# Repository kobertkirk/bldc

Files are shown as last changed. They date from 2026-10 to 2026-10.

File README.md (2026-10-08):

# 48 V / 35 A BLDC hub-motor controller

A KiCad hardware design plus STM32 firmware for a hall-sensored e-bike or scooter hub motor:

* **48 V nominal** (13S Li-ion, 54.6 V full). All power parts are rated 100 V and the TVS clamps at 60 V standoff.
* **35 A battery current limit** and 60 A phase current limit. Both are set in firmware and can be changed over UART.
* **Field-oriented control (FOC)** using the hall sensors, with angle interpolation, for quiet and smooth torque from standstill.
* **Throttle** input (standard 0.8–4.2 V hall throttle).
* **Momentary power button.** Press to switch on, hold for 2 s to switch off. Standby current is a few µA.
* **FWD/REV switch** input (switch to GND = reverse). There is also a **brake** input (switch to GND = cut power, optional regen).
* **UART telemetry and commands** (115200 8N1, 3.3 V). It streams every reading: voltage, currents, power, speed, temperatures, throttle, direction, faults, limits and energy used.
* **Auto-detect** measures motor R and L and learns the hall-sensor table, so any 120° hall hub motor works without setting angles by hand.

```
hardware/
  kicad/                 KiCad project (bldc48.kicad_pro): 4-sheet schematic + routed 4-layer PCB
  renders/               3D renders, routing/layer images, bldc48.glb 3D model
  bldc48-schematic.pdf   schematic as PDF
  bom.csv                bill of materials
  tools/                 circuit.py (the netlist source), generators, autorouting, connectivity checker,
                         render3d/ (VRML export + headless three.js renderer)
firmware/
  src/                   STM32G431 firmware (register-level, no HAL)
  sim/                   closed-loop PC simulation of the firmware against a hub-motor model
  cmsis/                 ST / ARM CMSIS headers (Apache-2.0)
```

> **Status — read this before building.** The schematic is complete and has been checked pin by pin (see
> [Verification](#verification)). The 90 × 95 mm (3.5 × 3.7 in) 4-layer, two-sided PCB (rev F) is **fully routed and passes KiCad
> DRC with 0 violations and 0 unconnected pads**. The power stage is placed by script around fixed columns; the signal
> routing was done by an autorouter (Freerouting), a small grid router for what it leaves open, and scripted copper
> pours, so have it reviewed before ordering. The firmware compiles and passes a detailed simulation, but it has
> **not been run on real hardware**. Bring the first board up with the current-limited procedure in
> [First power-up](#first-power-up).

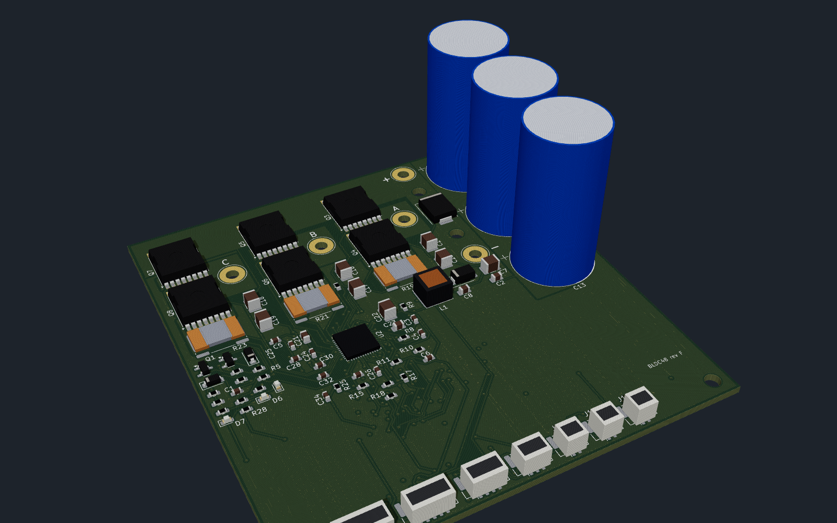
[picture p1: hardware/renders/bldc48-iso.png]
3D render of the routed board


---

## Block diagram

```
 BAT+ ──┬── TVS ── 3×1000µF + 6×2.2µF ──┬────────────────────────────────────┐
        │                                │  3 × half bridge (6 × IPT015N10N5) │
        │        ┌──────── DRV8353RS ────┴── GHx / GLx gate drive, SHx sense  ├── MOTOR A/B/C
        │        │  charge pump, 6-95 V buck → +5 V ── AP2112 → +3.3 V        │
        ├─Q1─────┤  3 × current-sense amp (G=20) ◄── 0.5 mΩ low-side Kelvin shunts
        │ latch  │  SPI config / fault readout, nFAULT
  PWR ──┘        └──► STM32G431CB ◄── ISENSE A/B/C, VBUS, throttle, NTCs
  button               │  ▲
              UART ◄───┘  └── halls, FWD/REV, brake, button
```

## Connectors

| Ref | Connector | Pin 1 | Pin 2 | Pin 3 | Pin 4 | Pin 5 | Pin 6 |
|---|---|---|---|---|---|---|---|
| J1 / J2 | 12 AWG solder pads (2.8 mm hole), right of the bridge | BAT+ / BAT− | | | | | |
| J3–J5 | 12 AWG solder pads, one per phase column | MOTOR A / B / C | | | | | |
| HALL | JST-GH 6 | +5 V | GND | Hall A | Hall B | Hall C | Motor NTC (optional) |
| THROTTLE | JST-GH 3 | +5 V | Signal | GND | | | |
| FWD/REV | JST-GH 2 | DIR (to GND = reverse) | GND | | | | |
| BRAKE | JST-GH 2 | BRAKE (to GND = braking) | GND | | | | |
| POWER_BTN | JST-GH 2 | PWR_SW (momentary to GND) | GND | | | | |
| UART | JST-GH 4 | +3.3 V out | TX (board → host) | RX (host → board) | GND | | |
| SWD | JST-GH 5 | +3.3 V | SWDIO | SWCLK | NRST | GND | |

All signal connectors are JST-GH (1.25 mm, latching) along the bottom edge. The power button and all signal wires
carry 3.3–5 V only, never battery voltage, so a cheap handlebar button is fine. Battery and phase wires are **12 AWG
silicone wire soldered straight into the plated pads** (strip 4 mm, push through, solder from the top; the pads are
via-stitched to the pours on all layers). Strain-relieve the wires to the case or heat plate with a cable tie so the
joints never carry the cable's weight. Put an **XT90-S anti-spark connector** and a **40 A fuse** in the battery
lead: the board has no reverse-polarity or inrush protection.

## First power-up

1. Flash the firmware over SWD (`cd firmware && make flash`).
2. Use a **bench supply at 48 V with a 2 A current limit**. Connect the UART (3.3 V USB-serial adapter at 115200 baud)
   and the halls, but leave the motor phases disconnected. Press the power button: the green LED blinks and telemetry
   lines (`$TLM,...`) appear. Type `status`. You should see vbus ≈ 48 V and `faults NOT_DETECTED`. Type `drv`:
   it should report `nFAULT=high` and zero status words (the DRV8353RS took its SPI settings).
3. Connect the motor phases (any order) and the hall connector. **Lift the wheel** so it spins freely.
4. Type `detect`. The wheel turns slowly forwards and then backwards (about 15 s total). Expected result:
   `detect OK: R = … mOhm, L = … uH, halls learned`. Type `save`.
   *(No UART cable? Hold the brake and full throttle for 3 s right after power-up, then release the throttle. Detect
   runs and saves automatically.)*
5. With the wheel still lifted, apply a little throttle. If the wheel turns the wrong way, `set dir_invert 1` then `save`.
6. Raise the supply limit (or switch to the battery) and set your limits, e.g. `set i_batt_max 35`, `set i_phase_max 60`,
   then `save`.

## UART interface

Lines end with CR or LF. Replies start with `>`. Telemetry lines start with `$TLM` (default every 100 ms;
change with `stream <ms>` or `stream off`).

```
$TLM,ms,state,faults,limits,vbus,ibus,power,ia,ib,ic,id,iq,iq_ref,erpm,rpm,mod,thr_v,thr_pct,dir,brake,hall,t_fet,t_mot,wh,ah,wh_regen
$TLM,105500,IDLE,0000,00,51.99,0.00,0.0,-0.01,0.01,-0.10,0.06,-0.00,0.00,2670,116.1,0.000,0.849,0.0,FWD,0,4,25.0,nan,10.912,0.2224,0.000
```
(Real line from the simulation: a coasting wheel at 116 rpm, 52 V, throttle at rest. `t_mot` is `nan` when no motor
NTC is enabled.)

| Command | What it does |
|---|---|
| `help` | List the commands |
| `status` | Human-readable state, faults, voltage, current, rpm, temperatures and control-loop CPU load |
| `tlm` / `hdr` | Print one telemetry line / print the column names |
| `stream <ms>` / `stream off` | Set the periodic telemetry rate, or turn it off |
| `get [name]` | Show one parameter, or all of them (including the learned hall angles) |
| `set <name> <value>` | Change a parameter in RAM |
| `save` / `defaults` | Write the config to flash / reload the defaults into RAM |
| `detect` / `detect r` / `detect l` / `detect hall` | Run auto-detect: everything, or only R, L or the hall table |
| `clear` | Clear latched faults |
| `drv` | DRV8353RS fault/status words, live and as captured at the last driver trip |
| `off` / `reboot` | Power the board off / restart the MCU |

Main parameters (`get` lists them all): `i_phase_max` 60 A, `i_batt_max` 35 A, `i_batt_regen` 5 A, `i_brake` 0 A (regen
on the brake input, off by default), `v_uv_start` 42 V / `v_uv_cut` 39 V (13S), `v_ov` 60 V, `t_fet_start` 80 °C /
`t_fet_max` 100 °C, `thr_min_v` 1.0 V / `thr_max_v` 4.0 V, `ramp_up` 100 A/s, `erpm_max` 0 (no speed limit),
`pole_pairs` 23 (only affects the rpm display), `mot_ntc_en` 0, `auto_off_min` 0.

| Fault bit (`faults` field, hex) | Meaning | Red LED blinks |
|---|---|---|
| 0x001 | overcurrent (80 A instantaneous phase-current trip) | 1 |
| 0x002 | overvoltage (> `v_ov`) | 2 |
| 0x004 | battery below `v_uv_cut` (no torque; information only) | short blink every 2 s |
| 0x008 | hall sensors invalid (000/111, e.g. unplugged) | 4 |
| 0x010 | throttle wire fault (< 0.4 V or > 4.7 V) | 5 |
| 0x020 | FET over-temperature or NTC broken | 6 |
| 0x040 | motor over-temperature (if `mot_ntc_en`) | 7 |
| 0x080 | halls not learned yet (run `detect`) | 8 |
| 0x100 | last detect failed | 9 |
| 0x200 | current-sensor offset out of range | 10 |
| 0x400 | throttle held at power-up | 11 |
| 0x800 | gate driver fault (DRV8353 nFAULT: VDS overcurrent, gate fault, UVLO, over-temperature); `drv` shows the fault words; the driver is re-initialised before it clears | 12 |

`limits` bits (why torque is reduced right now): 0x01 battery current, 0x02 phase current, 0x04 undervoltage
fold-back, 0x08 FET temperature, 0x10 motor temperature, 0x20 speed limit, 0x40 out of voltage (top speed),
0x80 stall protection.

Faults switch the gates off at once. They clear by themselves once the cause is gone and the throttle is back at
zero, so the motor can never restart while the throttle is held.

## How it works

**Power stage.** Six Infineon IPT015N10N5 (100 V, 1.5 mΩ, TOLL package) are driven directly by a TI DRV8353RS
smart gate driver (100 V, SPI). It sets the gate current itself (300 mA source / 600 mA sink, ≈100 ns edges on these
FETs), so there are no gate resistors; it adds 100 ns of its own dead time on top of the MCU's 400 ns and has a VDS
short-circuit trip (0.3 V, ≈110 A at 125 °C) behind the firmware's 80 A trip. Its SHx inputs sense each switch node
at the high-side source, right next to the gate pin. The MCU's TIM1 generates 20 kHz centre-aligned complementary
PWM (6-input mode). With the main output disabled, or with the driver asleep, all six gates are held low.

**Current sensing.** A 0.5 mΩ 4-terminal (Kelvin) shunt sits in each low-side source (Bourns CSS4J-4026R-L500F,
5 W). Its sense pads go to one of the DRV8353RS's three current-sense amplifiers (gain 20, biased to mid-rail), so full
scale is ±165 A per phase, comfortably above the 80 A hard trip (a compile-time check enforces this). The ADCs sample
while all three low-side FETs conduct, triggered by TIM1 channel 4 just before the counter peak. Above 90 % duty one
phase's low-side window is too short, so that phase's current is rebuilt from the other two (Ia + Ib + Ic = 0); the
duty is capped at 97 % so the bootstrap capacitors always recharge.

**Control.** The ADCs are triggered by the PWM timer once per period, and the injected-conversion interrupt runs the
FOC loop at 20 kHz:
- Clarke and Park transforms.
- PI current regulators on d and q, with BEMF/cross-coupling feed-forward and conditional-integration anti-windup.
- PWM delay compensation.
- Min/max SVPWM, capped at 97 % (low-side sensing needs a short low-side window; see above).

The rotor angle comes from the halls. Each hall edge gives the exact boundary angle, and between edges the angle is
extrapolated using a speed averaged over a full electrical revolution, which cancels sensor placement error. At
standstill the sector centre is used, which guarantees at least 86 % torque from the very first moment.

**Limits.**
- Throttle sets the torque (iq), with a ramp.
- Phase current limit.
- Battery current limit, from the power balance `I_bat = 1.5·vq·iq / Vbus`. In simulation it holds 34.8 A against a 35 A setting.
- Undervoltage, FET/motor temperature, speed and stall fold-backs.
- Instant 80 A hard trip and overvoltage trip.
- A direction change is only accepted once the wheel has stopped.

The motor flux linkage is learned while riding and used to re-engage smoothly at speed.

**Power latch.** When the button is pressed it pulls Q1's base (MMBTA92, 300 V PNP) low through 47 k and a diode.
Q1 enables the DRV8353RS's buck regulator. The MCU then sets PWR_HOLD, which turns on Q2 (MMBTA42) to keep Q1 on. A
BAT46W blocks the button-sense pull-up, so the latch cannot creep on through the unpowered 3.3 V rail. The buck's
enable divider also gives a ≈20 V UVLO. On shutdown the MCU first puts the gate driver to sleep, then releases the latch.

**Supplies.** The DRV8353RS's built-in 6–95 V buck (LM5008A core) makes +5 V for the halls, throttle and the
AP2112K-3.3 LDO; its 100 µH inductor is a 6 × 6 mm Bourns SRN6045TA. The gate drive comes from the DRV8353's own
charge pump (high side) and VGLS regulator (low side), so there is no 12 V rail and no separate gate-driver supply.
On power-up the firmware writes the driver's five configuration registers over SPI, reads them back and locks them;
a driver that does not answer stops the motor from starting (`drv` shows why).

## Verification

* `hardware/tools/check_netlist.py` exports KiCad's own netlist and checks that **every pin of all 133 parts** sits on
  the intended net, with no single-node nets. KiCad 7's CLI has no ERC, so this replaces it. A deliberately miswired
  pin is caught.
* KiCad DRC on the routed PCB: **0 violations, 0 unconnected pads, 0 footprint errors**, including the check that
  every footprint matches the stock KiCad library (report: `hardware/kicad/routing/drc.rpt`).
* `cd firmware && make sim` runs the **real** `motor.c`/`hall.c`/`cli.c` in closed loop against a model with:
  dead-time, PWM delay, ADC noise and offsets, 120° halls at an arbitrary offset, a 100 kg rider and a battery with
  internal resistance. It does this for two different motors. Results for motor 1:

  | Check | Result |
  |---|---|
  | Detect R / L / hall angles | 119.9 mΩ (120) / 259 µH (250) / 0.2° worst error |
  | Start from standstill, full throttle | torque ≥ 86 % of command from the first instant |
  | Peak phase current | 60.2 A (limit 60 A) |
  | Peak battery current (100 ms avg) | 34.3 A (limit 35 A) |
  | 120 A phase-short spike | hard trip, gates off within 200 µs |
  | Gate-driver fault (nFAULT) while riding | gates off within 2 PWM periods, driver re-initialised before restart |
  | High-duty current rebuild (low-side shunts) | exercised continuously at top speed, no faults |
  | Current-loop tracking | 0.47 A rms |
  | Top speed, 26″ wheel | ≈ 39 km/h (voltage limited) |
  | Coast, re-engage at speed, reverse, brake, throttle-wire break, hall unplug, low battery, overvoltage | all pass |

## Building the firmware

```
sudo apt install gcc-arm-none-eabi libnewlib-arm-none-eabi   # plus stlink-tools or openocd
cd firmware
make            # build/bldc48.elf/.bin/.hex  (~38 KB flash)
make flash      # st-flash, or: make flash-ocd
make sim        # closed-loop simulation on the PC
```

## Regenerating the hardware

The schematic, PCB and BOM are generated from `hardware/tools/circuit.py`, using symbols and footprints from the stock
KiCad libraries. After you edit the circuit, run `hardware/tools/regen.sh`. It needs KiCad ≥ 7; KiCad 8 and 9 open the
files directly.

`regen.sh` only places the parts. The board was then routed with
`hardware/tools/route_pcb.py --legacy --no-optimize --passes 30 --freerouting freerouting-1.9.0.jar`. This script:
- keeps tracks off the inner layers under the FETs, DC-link caps and shunts, and off the outer layers across the
  switch-node and low-side copper (rule areas)
- gives every GND pad outside the power stage its own via into the solid In1 plane, and puts a fixed "sense tap" via
  in each switch node next to the high-side gate pin for the DRV8353's SHx input
- routes the signals with Freerouting (headless, under `xvfb-run`)
- imports the result (KiCad 7 can only import a Specctra session from its GUI, so the script parses the file
  itself and restores any layer-change vias the router left out)
- `astar_route.py` is a small 4-layer grid router for connections Freerouting leaves open, keeping clear of the
  power copper
- adds the GND / +48V / +3V3 planes, the 35 A outer-layer pours and via arrays in the power pads, routes anything
  still cut off into its own pour, and stitches pour islands to the planes
- fills the zones and writes a DRC report

The routing session is saved in `hardware/kicad/routing/bldc48.ses` (with the DRC report next to it); `route_pcb.py
--ses ../kicad/routing/bldc48.ses` rebuilds a routed board from it, taking the part positions from the session. The
committed `bldc48.kicad_pcb` is the reference: a rebuild can differ in a few fan-out vias and then needs a DRC pass.

`hardware/tools/render3d/render.sh` exports the board to VRML with the KiCad 3D models (plus simple stand-ins for the
JST-GH connectors, the SRN6045 inductor and the DRV8353 QFN, whose models are not in the KiCad 7 library) and renders
the PNGs in `hardware/renders/` with three.js in headless Chromium; `layers.sh` makes the copper-layer images.

**Note:** regenerating overwrites placement and routing. For changes after this point, edit the board in KiCad and use
Tools → Update PCB from Schematic. The footprints are already linked to their schematic symbols for that.

### Board

| Overview | Power stage |
|---|---|
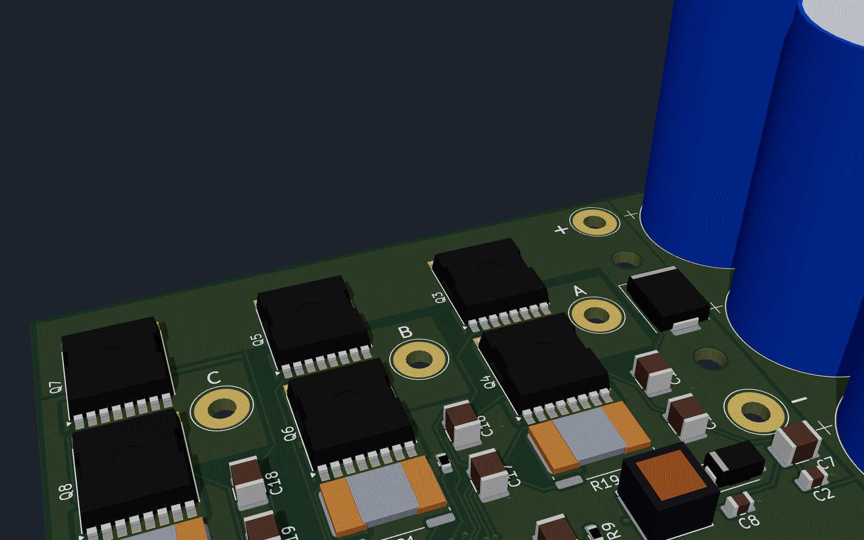
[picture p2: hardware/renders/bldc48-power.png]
power stage
| overview |  |
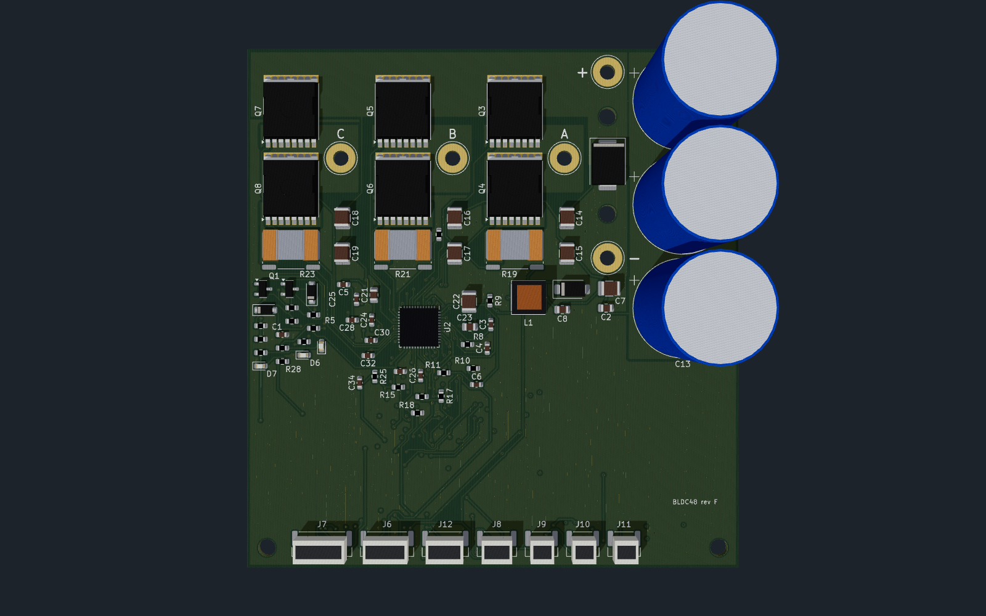
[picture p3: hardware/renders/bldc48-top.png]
top
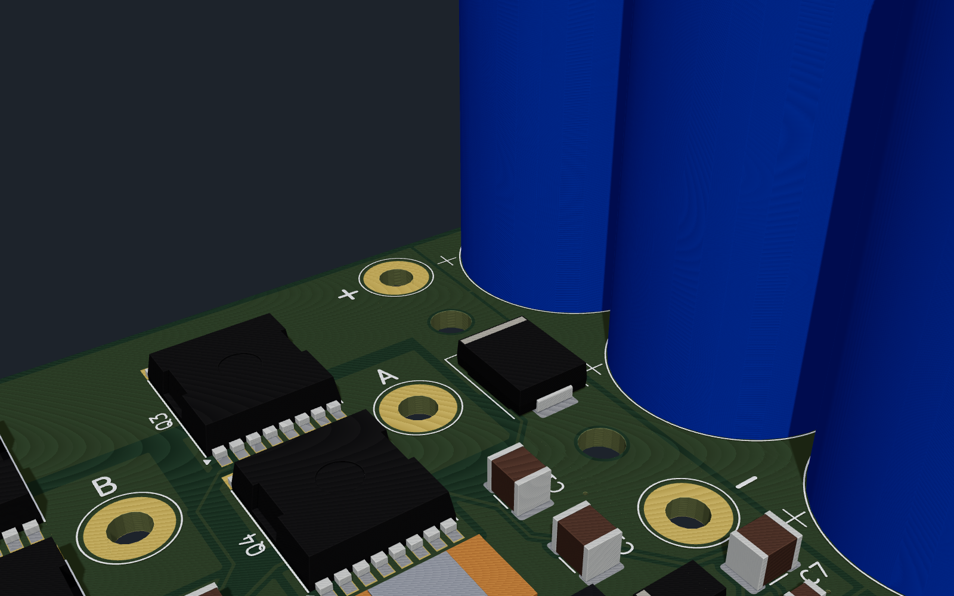
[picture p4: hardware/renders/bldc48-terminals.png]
wire pads
|  |  |

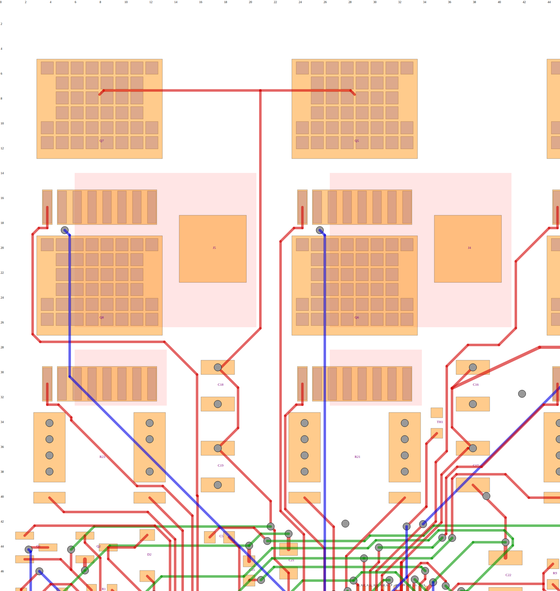
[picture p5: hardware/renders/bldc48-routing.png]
routing
Routing (tracks only, pours hidden): 

Copper layers: [top](hardware/renders/bldc48-layer-top.png) · [inner 1, GND](hardware/renders/bldc48-layer-in1.png) ·
[inner 2, +48V/+3V3](hardware/renders/bldc48-layer-in2.png) · [bottom](hardware/renders/bldc48-layer-bottom.png)

Stackup as built: F.Cu power stage, gate drive and signals, with pours (switch nodes, low-side sources, +48V bus,
GND fill) · In1.Cu solid GND plane · In2.Cu +48V under the power stage and +3V3 fill elsewhere, plus signals ·
B.Cu the same high-current pours under the bridge, the MCU and I/O parts, and signals. The inner planes are unbroken
under the FETs, DC-link caps and shunts. 1666 track segments and 269 vias; each switch-node and low-side pour is one
unbroken piece on both outer layers (checked by script).

## Rev F: DRV8353RS, 90 × 95 mm

Rev E (180 × 69.5 mm) was still too big. Rev F redesigns the circuit around one TI DRV8353RS smart gate driver and
puts the parts on both sides of a **90 × 95 mm** board, **68 % of rev E's area** (3.5 × 3.7 in instead of
7.1 × 2.7 in).
- **One chip instead of eight.** The DRV8353RS replaces the three LM5109B gate drivers, the three INA240A1 current
  amplifiers and both LM5164 bucks: it has the gate drive (charge pump + low-side regulator, no 12 V rail), three
  current-sense amplifiers and a 6–95 V buck that makes the +5 V rail.
- **Low-side shunts.** The three 0.5 mΩ Kelvin shunts now sit in the low-side sources (the DRV8353's amplifiers are
  low-side). The firmware samples while all low-side FETs conduct and rebuilds the third current above 90 % duty.
- **Three 1000 µF / 100 V** cans (Aishi ERS1KM102M35OT, 18 × 35 mm) in a column next to the bridge, plus two 2.2 µF
  ceramics straight across each half bridge. 3000 µF is still 1.7 × rev B's 1760 µF. Cans can be bent over before
  soldering if the case is low.
- **12 AWG wires soldered straight into the board** instead of M5 bolt terminals: battery pads at the right of the
  bridge, one motor pad per phase column. JST-GH (1.25 mm, latching) for all signal connectors.
- **Two-sided assembly.** Power stage, gate driver, supply and connectors on top; MCU, its filters and the I/O
  conditioning on the bottom, outside the heat-plate area under the FETs.
- The phase columns run C-B-A from left to right, following the DRV8353's pin order, so no phase's gate drive crosses
  another's. The labels are only names: auto-detect learns the hall/phase order.
- Signal tracks 0.2 mm with 0.15 mm clearance (JLCPCB's 4-layer minimum is 0.09 mm). The +48 V and switch-node pours
  keep 0.5 mm.

Each phase is a column: high-side FET, low-side FET, shunt, two 2.2 µF ceramics and the motor wire pad on the switch
node beside the FETs. The heat plate goes under the bridge (bottom side, no parts there).

## Ordering from JLCPCB (rough cost)

These are estimates from JLCPCB's published pricing and LCSC part prices in October 2026. Upload the files to get a
real quote, because their prices change often.

| Item (order of 5 assembled boards) | Approx. |
|---|---|
| 4-layer PCB 90 × 95 mm, 1.6 mm, 2 oz outer copper, 5 pcs | $30–50 |
| PCBA setup + stencils, **two-sided** (standard PCBA: both sides placed) | ≈ $50 |
| "Extended" LCSC part loading fee, ≈ $3 per unique part type (~22 types) | ≈ $65 |
| SMT + through-hole joints (≈ 530 SMT + 6 THT per board) | ≈ $10 |
| Parts (≈ $30/board, all from LCSC; the DRV8353RS is ≈ $6, the six FETs ≈ $15) | ≈ $150 |
| Shipping (DHL / FedEx) | $20–35 |
| **Total for 5** | **≈ $325–360, about $65–72 per board** |

The five 12 AWG wire pads are left for you to solder (wires are not assembled). Choosing JLCPCB's "economic" PCBA
is not possible for a board with parts on both sides; if cost matters more than size, rev E (one-sided, 180 ×
69.5 mm) is in the git history.

Every part in the BOM has an LCSC part number or is a generic resistor/capacitor/diode/connector that LCSC stocks in
quantity, so JLCPCB can build the whole board.
- The bulk capacitors are Aishi ERS1KM102M35OT (C724666): 1000 µF/100 V, 18 × 35 mm, 7.5 mm pitch, 10 000 h at
  105 °C. Aishi's "1K" voltage code is 100 V in its own scheme ("1B" is 80 V), and LCSC lists the part as 100 V.
- Ripple: at 35 A battery current the DC link carries roughly 17 A rms, ≈ 5.7 A per can with three cans; the ceramics
  take the high-frequency part. Expect the cans to run warm in sustained hard use: watch their temperature, or lower
  `i_batt_max` / `i_phase_max`, or fit higher-ripple parts (Panasonic EEU-FC2A102, Nichicon UHE2A102).
- The shunts are Bourns CSS4J-4026R-L500F (LCSC/JLCPCB C2076423, 0.5 mΩ ±1 %, 5 W, 4-terminal). The footprint is
  KiCad's `R_Shunt_Isabellenhuette_BVR4026` (same 10.6 mm span and pad layout).
- The DRV8353RS is TI DRV8353RSRGZR (LCSC C506246), VQFN-48 7 × 7 mm with an exposed pad. Its exposed pad has a
  thermal-via array into the GND plane; ask for the vias to be tented or plugged.
- Check that every part you order has a 100 V rating where the BOM needs one: the TOLL FETs, DRV8353RS, the
  1000 µF/100 V caps, the 100 V ceramics and the SS110 diode. Do not let the assembly service substitute
  lower-voltage parts.
- Set the stackup to 2 oz outer copper. JLCPCB's cheap 4-layer offer is 1 oz.
- JLCPCB only assembles from 2 boards upward, and the setup and part-loading fees are charged once per order, so
  most of the cost of a small order is fees.
- Board size: 90 × 95 mm (3.5 × 3.7 in), 1.6 mm thick. The 1000 µF caps are the tallest parts, so the assembled
  board is about 37 mm tall (less if the caps are bent over). Four M3 holes: two in the battery strip, two in the
  bottom corners.

## Design review (rev B, kept for reference)

A full review of rev A found and fixed these problems:

| Problem in rev A | Fix in rev B |
|---|---|
| BAT+ / BAT− were 5×10 mm SMD solder pads 7.5 mm apart (≈2.5 mm copper gap), 6 mm in from the edge; SMD pads tear off under 12 AWG wire strain | M5 plated bolt terminals for ring lugs, via-stitched to the planes, on the left edge 36 mm apart, TVS between them, large BAT+/BAT− silkscreen |
| Motor pads sat 38 mm below their shunts | M5 bolt terminals on the bottom edge straight below each shunt, labelled MOTOR A/B/C |
| **Overcurrent trip could never fire**: INA240A2 (gain 50) saturated the ADC at ±66 A, below the 80 A trip | INA240A1 (gain 20, ±165 A full scale); a compile-time assert keeps the trip inside the measurable range; new simulation test trips on a 120 A spike within 200 µs |
| INA240 inputs tapped the switch-node/phase copper anywhere, so pour resistance corrupted the current reading | 4-terminal Kelvin shunt (Bourns CSS4J-4026R-L500F, 5 W) with dedicated sense pads to the amplifier |
| FET temperature sensor TH1 was in the board corner, far from the FETs | TH1 next to the middle low-side FET |
| DC-link ceramics ~32 mm from the low-side sources (large switching loop) | Ceramics directly under each low-side FET's source leads; both FETs drain-tab up so the switch node is a short gap between them |
| Low-side gate on the far side of the FET from its driver | Driver beside the FET pair, both gate pins facing it |
| Router ran signals on In2 straight under the FETs, slotting the +48V plane between the drains and the ceramics | Rule area keeps tracks off both inner layers under the FETs, ceramics and shunts |
| 10 Ω gate resistors: ≈170 ns edges, ≈2.9 W switching loss per high-side FET at 35 A | 4.7 Ω: ≈100 ns edges, ≈1.7 W |
| 6 × 220 µF carried ≈2.8 A rms ripple each | 8 × 220 µF, ≈2.1 A each |
| Pours sized from pad centres missed the TOLL drain tabs' real outline (vias in the tabs connected on one layer only) | Pours drawn from the measured pad outlines; inner planes solid-connected to the power terminals |

Checks run on rev B: every symbol pin matches its footprint pad (29 symbol/footprint pairs), every pin of all 174
parts is on its intended net, every footprint matches the stock KiCad library, KiCad DRC 0 violations, firmware
simulation passes on two motors including the new overcurrent test.

## PCB layout rules

* Use 4 layers with 2 oz outer copper. Run 35 A battery and phase paths as wide pours on two or more layers,
  stitched with many vias. Rule areas keep signal tracks off the switch-node and low-side copper on the top layer;
  do not route across them.
* Keep each half-bridge loop (high FET → low FET → 2.2 µF ceramics) as small as possible. The bulk caps sit right
  next to the bridge.
* Give the FET drain/source pads thermal-via arrays down to the bottom pours. Bolt the board to an aluminium plate or
  the case through a thermal pad under the bridge (no parts on the bottom there). At 35 A, expect roughly 6–10 W of
  losses at full load.
* Route each shunt's sense pads (pins 2/3 of the 4-terminal shunt) to the DRV8353's SPx/SNx as a pair, with the
  1 nF filter caps at the driver.
* Keep the gate-drive traces short and away from the switch nodes; the DRV8353's SHx pin senses each switch node at
  the high-side source, next to the gate pin. Use one solid ground plane, and keep the MCU and analog parts away from
  the switching nodes.
* Keep TH1 (the NTC) next to the low-side FETs, which run hottest.

## Things to double-check against datasheets before ordering

* The DRV8353RS buck (LM5008A core) component values (RT / shutdown divider, 100 µH inductor, 4.02 k / 4.02 k
  feedback divider, 8.2 k / 47 nF / 330 pF ripple injection) were chosen with the datasheet formulas but not run
  through TI WEBENCH.
* The DRV8353's gate-current setting (300 mA / 600 mA) and the gate-drive trace lengths: the longest gate trace is
  ≈ 60 mm (phase C high side). The driver's current-mode drive tolerates this, but look at the gate waveform on the
  first board and lower IDRIVE if it rings.
* The bulk capacitor ripple rating (≈ 5.7 A rms per can at 35 A battery current; see above).
* Choose `v_uv_*` for your pack. The defaults are for 13S.

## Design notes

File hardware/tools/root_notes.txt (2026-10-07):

DESIGN SUMMARY
- Battery: 48 V nominal (13S Li-ion, 54.6 V full). Abs. max 60 V (TVS SMCJ60CA, 100 V FETs/drivers/bucks).
- Battery current limit 35 A (firmware, from FOC power estimate). Phase current limit 60 A (firmware), hard trip 80 A.
- Power stage: 6 x IPT015N10N5 (100 V, 1.5 mOhm, TOLL) driven by 3 x LM5109B half-bridge drivers @ 20 kHz, 4.7 Ohm gate resistors.
- Current sensing: in-line 0.5 mOhm 4-terminal (Kelvin) phase shunts + INA240A1 (G=20, mid-rail ref) -> +/-165 A full scale.
- Control: STM32G431CB @170 MHz, hall-sensor FOC with angle interpolation; hall/R/L auto-detect over UART.
- Supplies: LM5164 48->12 V (gate drive), LM5164 48->5 V (halls/throttle), AP2112 5->3.3 V (logic).
- Soft power: momentary button to GND wakes the bucks via Q1, MCU latches with PWR_HOLD; long press = off.
- I/O: hall + motor NTC (JST-PH6), throttle (PH3), FWD/REV switch (PH2), brake (PH2), power button (PH2),
  UART 115200 8N1 3.3 V (PH4: 3V3, TX, RX, GND), SWD (1x5 header).
LAYOUT RULES: 2 oz copper min (4 layer preferred), bus/phase pours >= 10 mm wide, FET tabs on thermal-via arrays
to an aluminium heat spreader, Kelvin-route INA240 inputs from the shunt pads, DC-link ceramics at each half bridge.

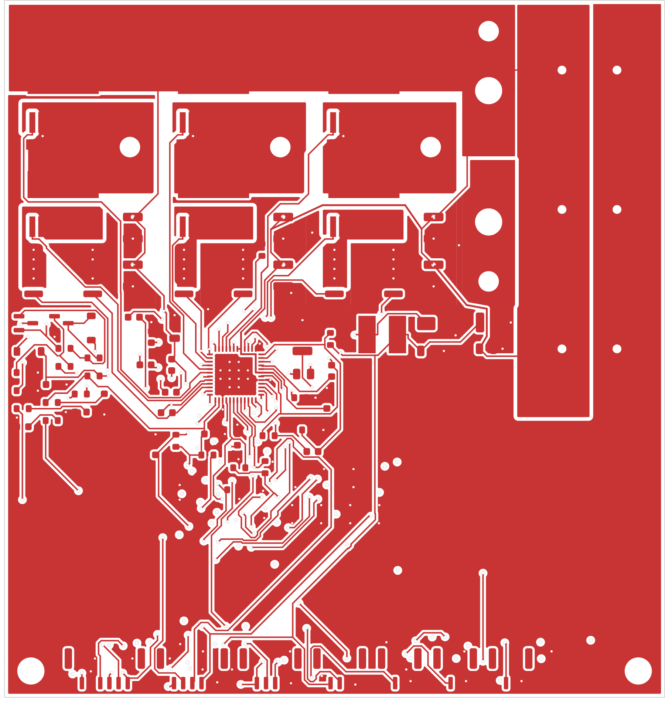
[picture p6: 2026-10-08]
hardware/renders/bldc48-layer-top.png

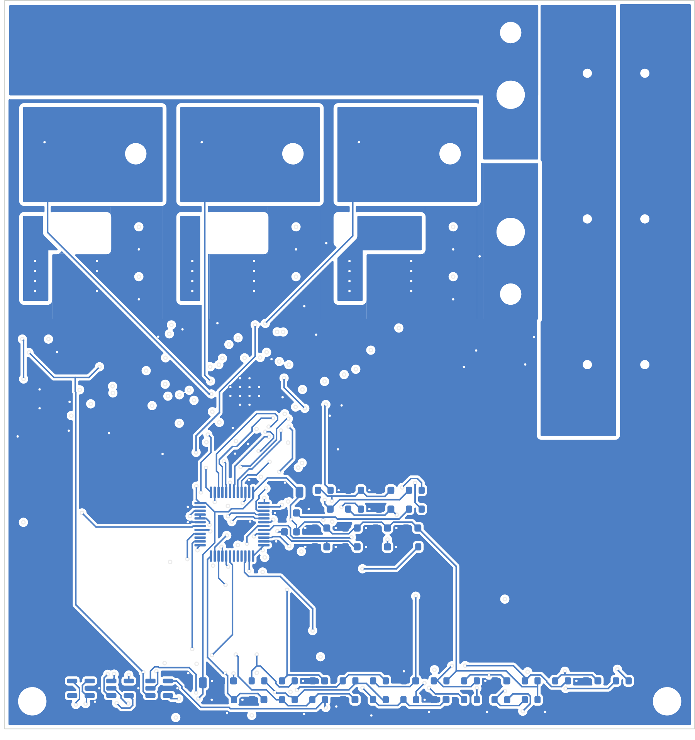
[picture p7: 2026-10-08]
hardware/renders/bldc48-layer-bottom.png

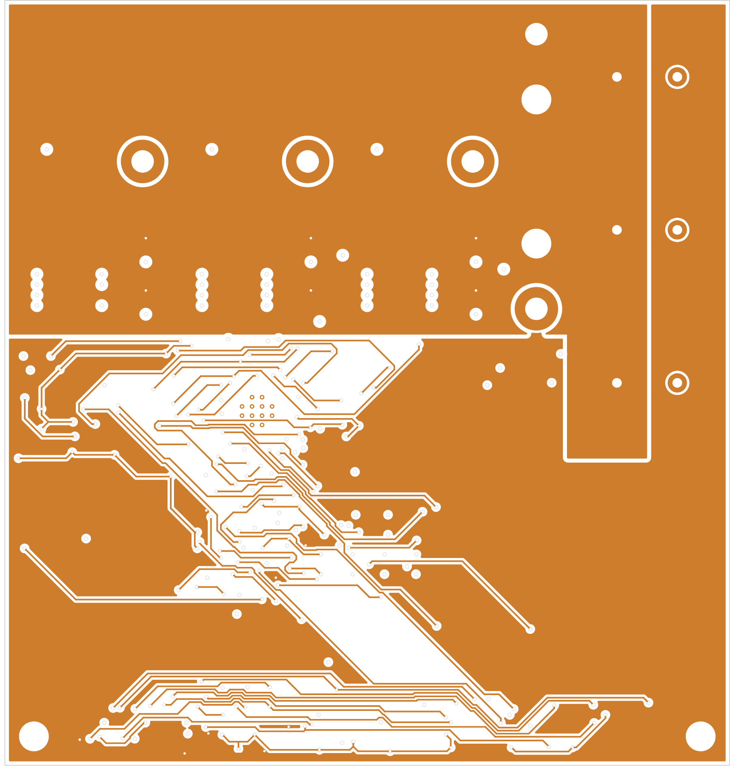
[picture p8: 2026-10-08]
hardware/renders/bldc48-layer-in2.png

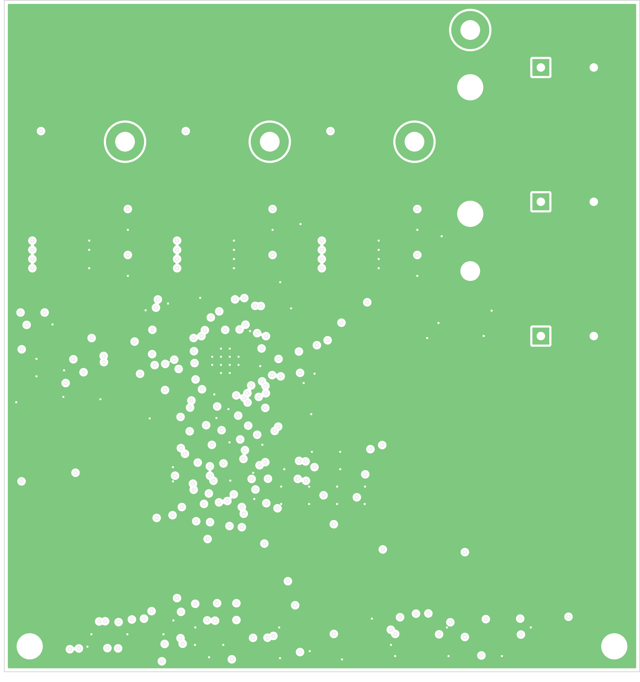
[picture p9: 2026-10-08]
hardware/renders/bldc48-layer-in1.png

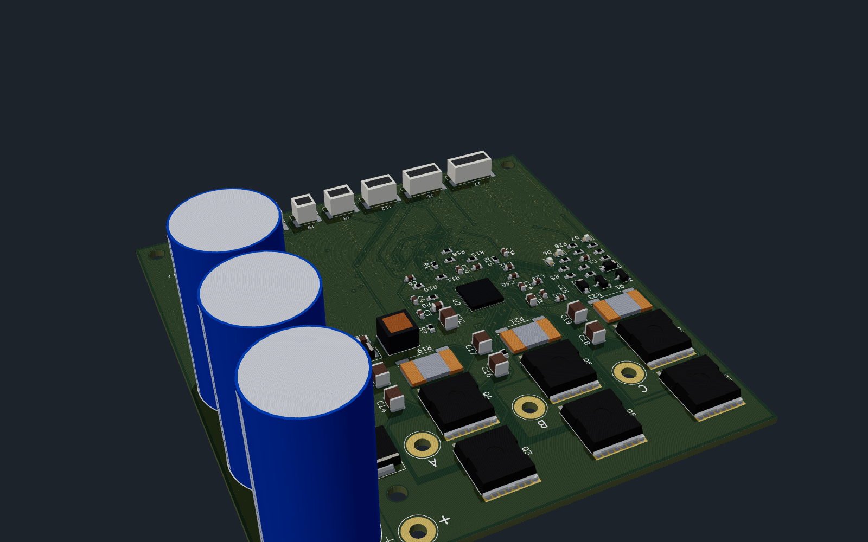
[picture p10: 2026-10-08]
hardware/renders/bldc48-rear.png

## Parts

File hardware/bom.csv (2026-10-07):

Qty | Value | Footprint | Part / notes | References
3 | 1000u/100V | CP_Radial_D18.0mm_P7.50mm | Aishi ERS1KM102M35OT (LCSC C724666), 18x35 mm, 7.5 mm pitch, 105 C 10000 h | C11 C12 C13
12 | 100n | C_0603_1608Metric |  | C27 C34 C35 C36 C37 C38 C41 C42 C46 C47 C48 C49
1 | 100n/100V | C_0805_2012Metric | X7R 0805 100V | C21
3 | 10n | C_0603_1608Metric |  | C1 C3 C20
9 | 1n | C_0603_1608Metric |  | C28 C29 C30 C31 C32 C33 C43 C44 C45
4 | 1u | C_0603_1608Metric |  | C4 C9 C26 C40
1 | 1u/100V | C_0805_2012Metric |  | C2
2 | 1u/16V | C_0603_1608Metric |  | C24 C25
7 | 2.2u/100V | C_1210_3225Metric | X7R 1210 100V (e.g. GRM32ER72A225KA35) | C14 C15 C16 C17 C18 C19 C22
1 | 22u/10V | C_1210_3225Metric | X5R/X7R 1210 10V | C7
1 | 330p | C_0603_1608Metric |  | C6
3 | 4.7u | C_0805_2012Metric |  | C8 C10 C39
1 | 47n | C_0603_1608Metric |  | C5
1 | 47n/100V | C_0805_2012Metric |  | C23
1 | 1N4148W | D_SOD-123 | 100V signal diode SOD-123 | D2
1 | BAT46W | D_SOD-123 | 100V Schottky SOD-123 | D3
2 | ESDA6V1-5SC6 | SOT-23-6 | ST ESDA6V1-5SC6 (LCSC C6650) | D8 D9
2 | GREEN | LED_0603_1608Metric |  | D5 D6
1 | RED | LED_0603_1608Metric |  | D7
1 | SMCJ60CA | D_SMC | TVS 60V standoff, 1500W, SMC (Littelfuse, LCSC C151290) | D1
1 | SS110 | D_SMA | 100 V 1 A Schottky, SMA (e.g. MDD SS110) | D4
1 | 600R@100MHz | L_0603_1608Metric |  | FB1
4 | M3 | MountingHole_3.2mm_M3 |  | H1 H2 H3 H4
1 | BAT+ | SolderWire_12AWG_D2.8mm_OD5.4mm | 12 AWG wire, soldered | J1
1 | BAT- | SolderWire_12AWG_D2.8mm_OD5.4mm | 12 AWG wire, soldered | J2
1 | BRAKE | JST_GH_BM02B-GHS-TBT_1x02-1MP_P1.25mm_Vertical | JST BM02B-GHS-TBT (1.25 mm, latching) | J10
1 | FWD/REV | JST_GH_BM02B-GHS-TBT_1x02-1MP_P1.25mm_Vertical | JST BM02B-GHS-TBT (1.25 mm, latching) | J9
1 | HALL | JST_GH_BM06B-GHS-TBT_1x06-1MP_P1.25mm_Vertical | JST BM06B-GHS-TBT (1.25 mm, latching) | J7
1 | MOTOR_A | SolderWire_12AWG_D2.8mm_OD5.4mm | 12 AWG wire, soldered | J3
1 | MOTOR_B | SolderWire_12AWG_D2.8mm_OD5.4mm | 12 AWG wire, soldered | J4
1 | MOTOR_C | SolderWire_12AWG_D2.8mm_OD5.4mm | 12 AWG wire, soldered | J5
1 | POWER_BTN | JST_GH_BM02B-GHS-TBT_1x02-1MP_P1.25mm_Vertical | JST BM02B-GHS-TBT (1.25 mm, latching) | J11
1 | SWD | JST_GH_BM05B-GHS-TBT_1x05-1MP_P1.25mm_Vertical | JST BM05B-GHS-TBT (1.25 mm, latching) | J6
1 | THROTTLE | JST_GH_BM03B-GHS-TBT_1x03-1MP_P1.25mm_Vertical | JST BM03B-GHS-TBT (1.25 mm, latching) | J8
1 | UART | JST_GH_BM04B-GHS-TBT_1x04-1MP_P1.25mm_Vertical | JST BM04B-GHS-TBT (1.25 mm, latching) | J12
1 | 100u | L_Bourns_SRN6045TA | Bourns SRN6045TA-101M or eq. (100 uH, Isat >= 0.5 A, 6x6 mm) | L1
6 | IPT015N10N5 | Infineon_PG-HSOF-8-1 | Infineon IPT015N10N5ATMA1 (LCSC C108964) | Q3 Q4 Q5 Q6 Q7 Q8
1 | MMBTA42 | SOT-23 |  | Q2
1 | MMBTA92 | SOT-23 |  | Q1
3 | 0.5m | R_Shunt_Isabellenhuette_BVR4026 | Bourns CSS4J-4026R-L500F (LCSC C2076423), 0.5 mOhm 1% 5 W | R19 R21 R23
5 | 100R | R_0603_1608Metric |  | R20 R22 R24 R43 R44
6 | 100k | R_0603_1608Metric |  | R1 R4 R6 R8 R13 R18
10 | 10k | R_0603_1608Metric |  | R3 R5 R15 R17 R25 R26 R35 R39 R41 R45
1 | 12k | R_0603_1608Metric |  | R37
1 | 150k | R_0603_1608Metric |  | R7
8 | 1k | R_0603_1608Metric |  | R27 R28 R30 R32 R34 R36 R40 R42
4 | 2.2k | R_0603_1608Metric |  | R12 R29 R31 R33
1 | 22k | R_0603_1608Metric |  | R38
2 | 4.02k | R_0603_1608Metric |  | R9 R10
1 | 4.7k | R_0603_1608Metric |  | R16
1 | 47k | R_0603_1608Metric |  | R2
1 | 5.6k | R_0603_1608Metric |  | R14
1 | 8.2k | R_0603_1608Metric |  | R11
1 | 10k B3435 | R_0603_1608Metric | Murata NCP18XH103F03RB (LCSC C13564) | TH1
1 | AP2112K-3.3 | SOT-23-5 | Diodes AP2112K-3.3TRG1 (LCSC C51118) | U1
1 | DRV8353RS | TI-RGZ-48-QFN | TI DRV8353RSRGZR (LCSC C506246) | U2
1 | STM32G431CBT6 | LQFP-48_7x7mm_P0.5mm | ST STM32G431CBT6 (LCSC C529355) | U3

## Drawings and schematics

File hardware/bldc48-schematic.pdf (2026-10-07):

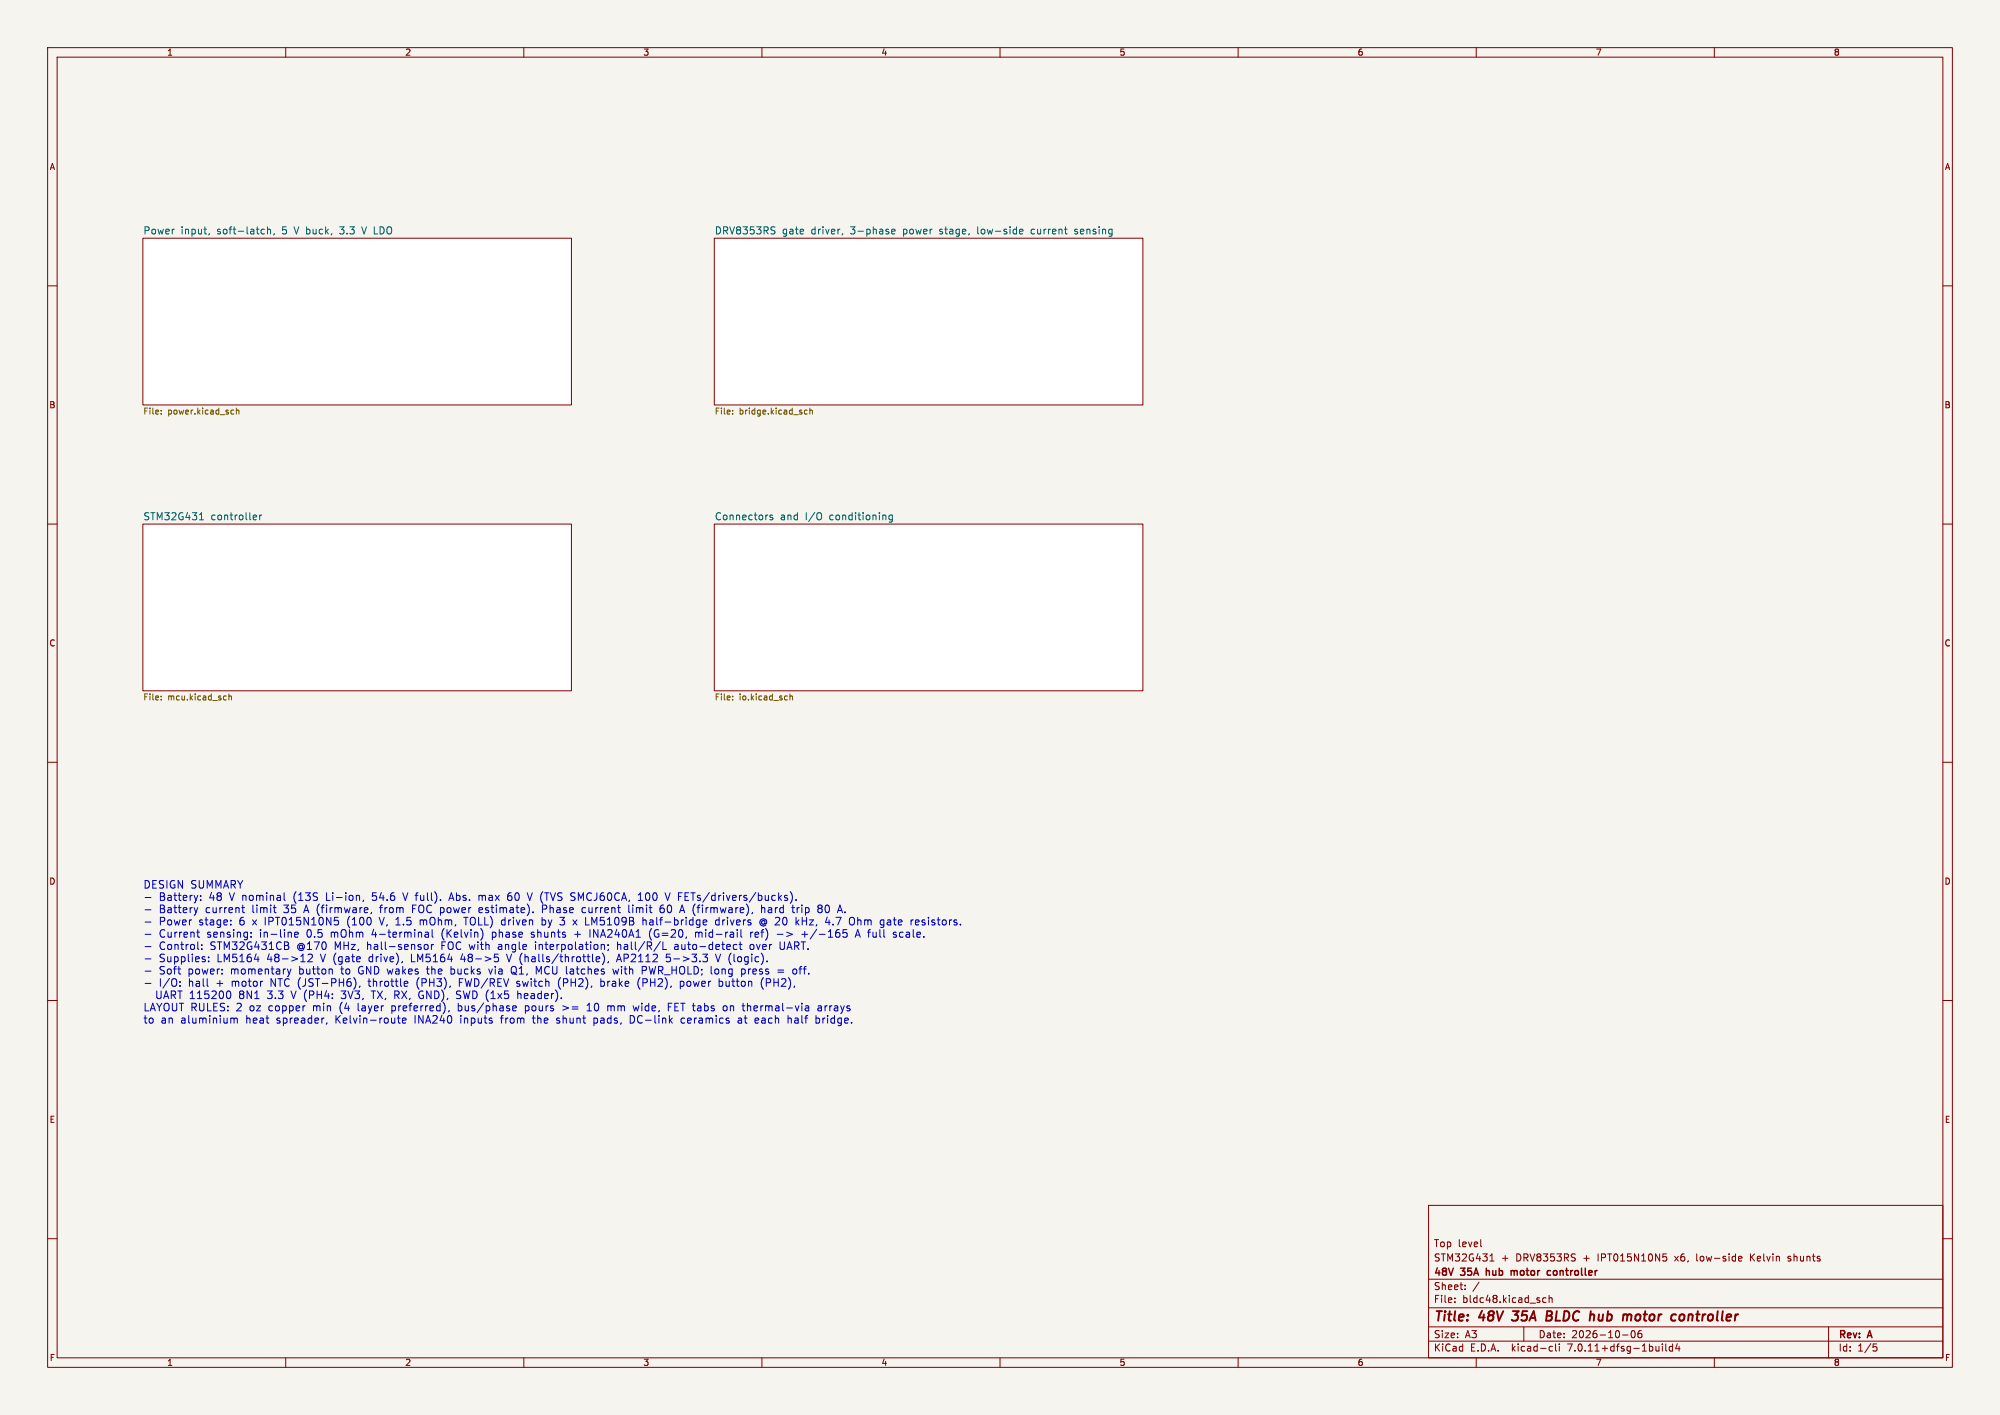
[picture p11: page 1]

UART 115200 8N1 3.3 V (PH4: 3V3, TX, RX, GND), SWD (1x5 header).

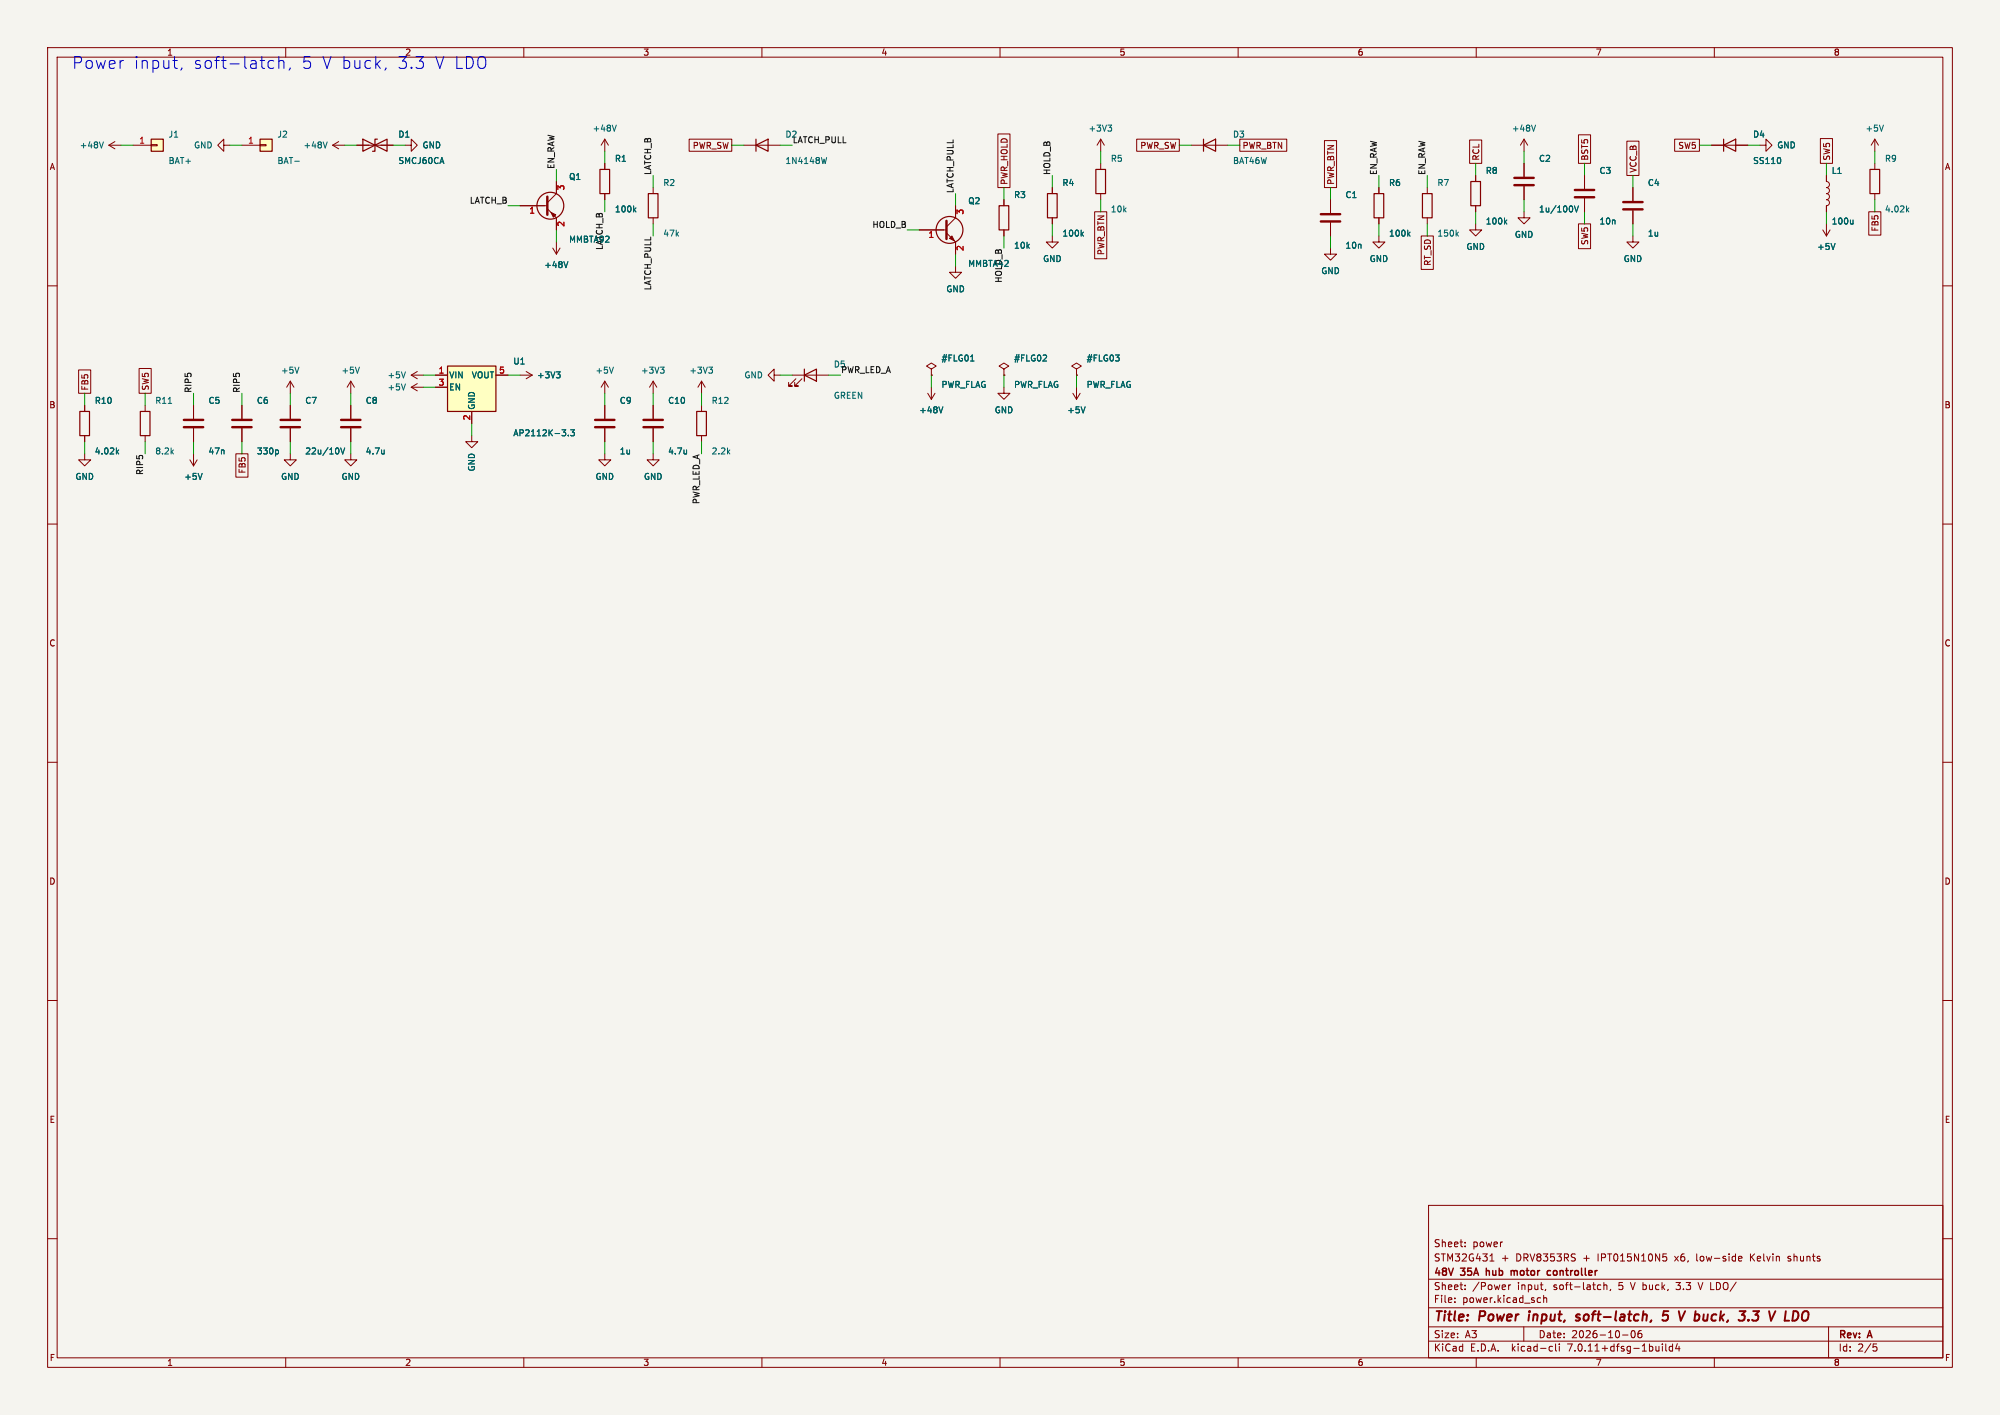
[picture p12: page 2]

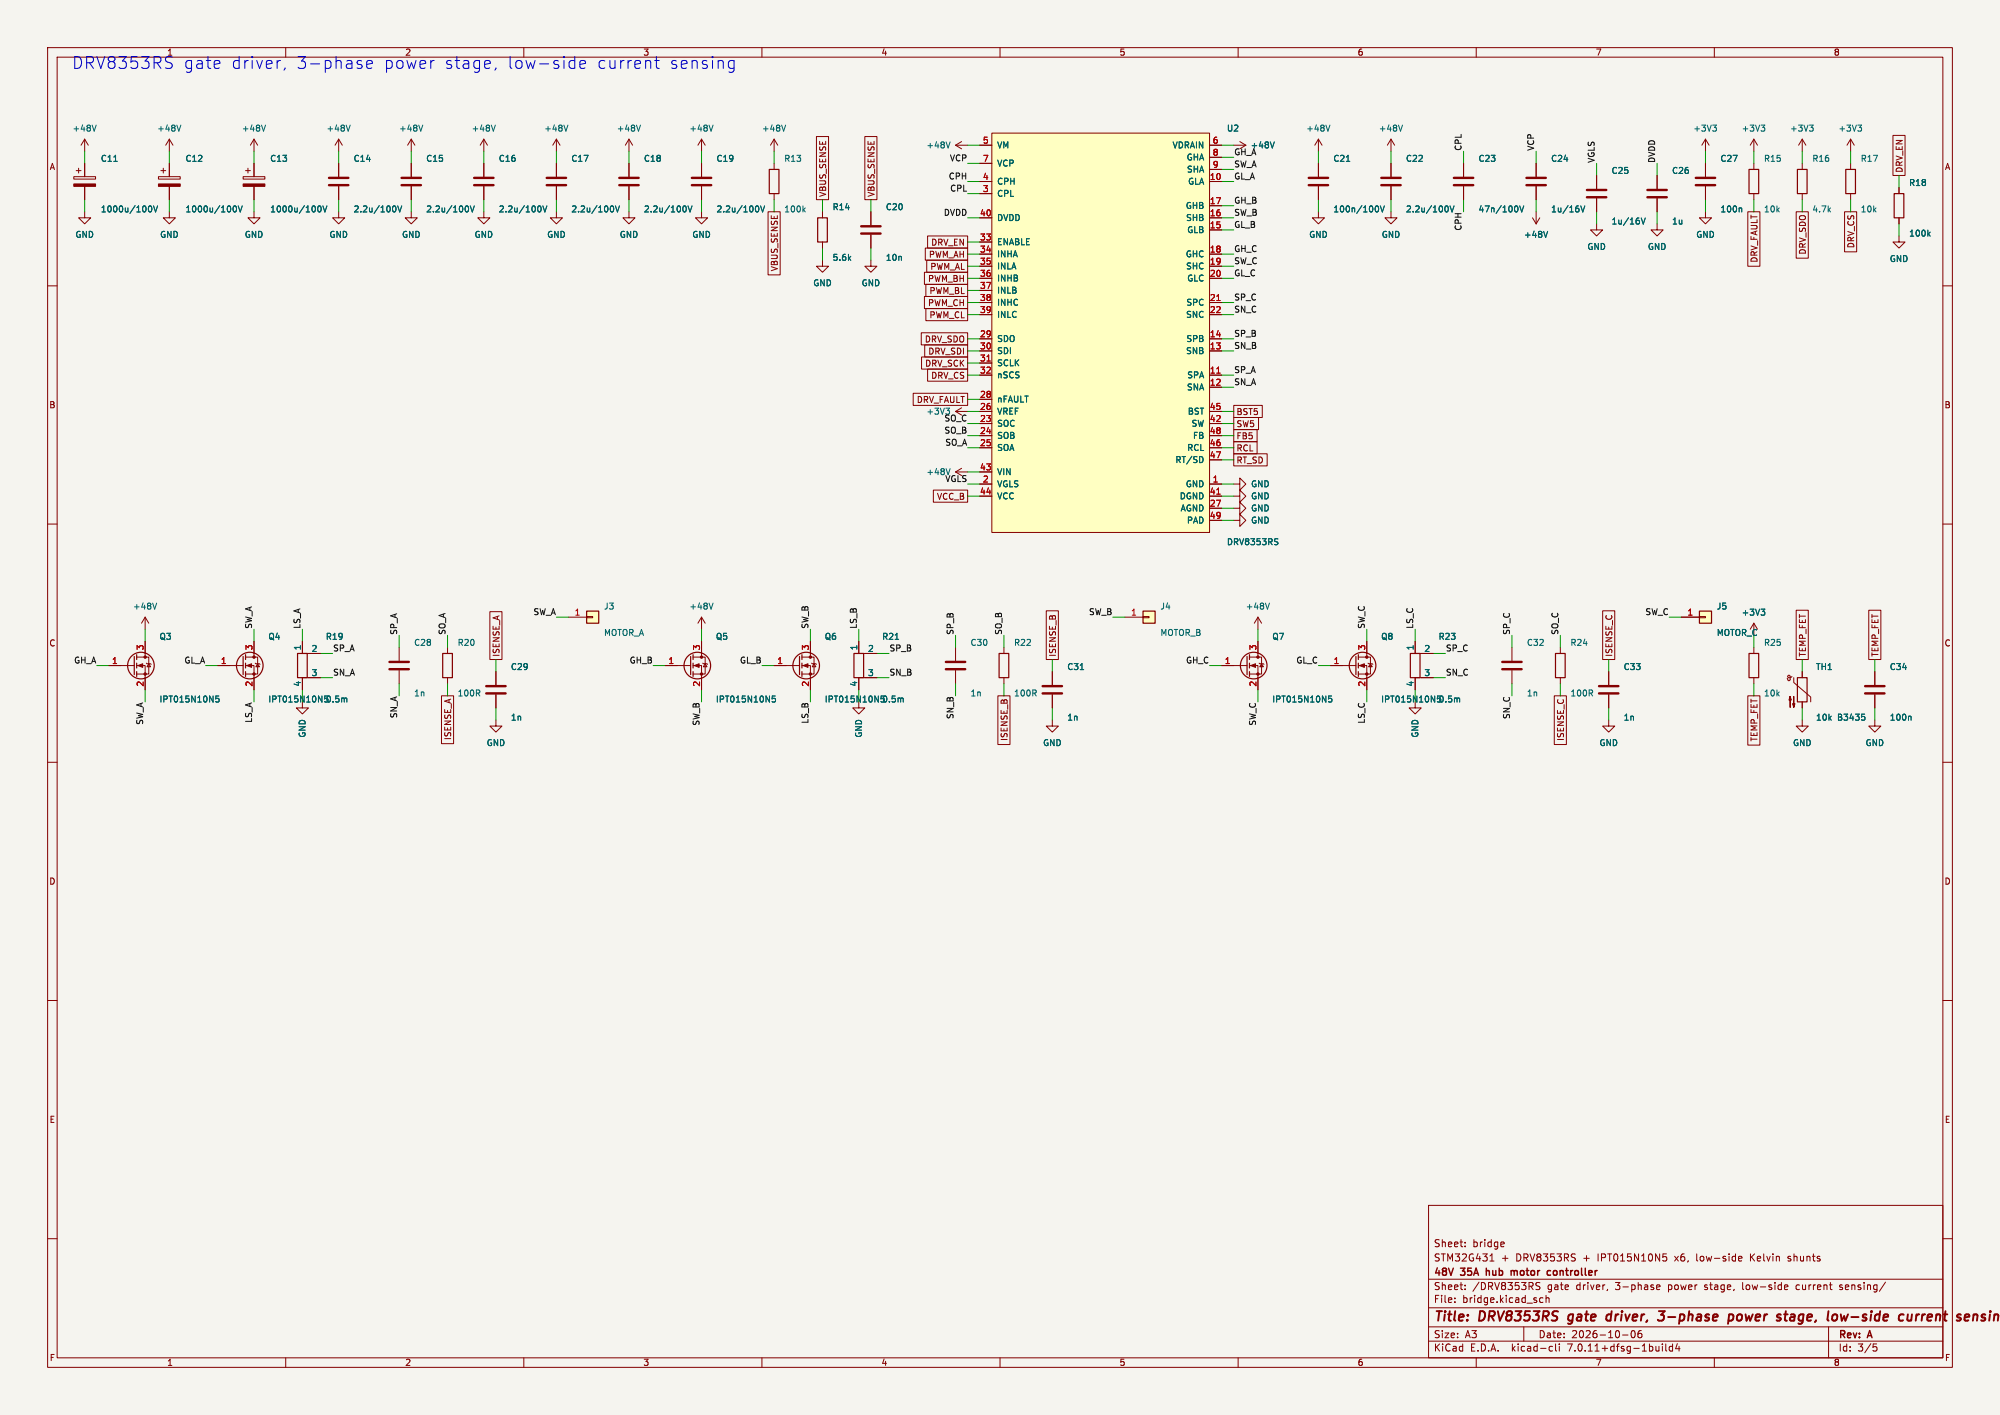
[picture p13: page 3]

CPH
nFAULT 28 SDO 29 CPL 3 SDI 30 SCLK 31

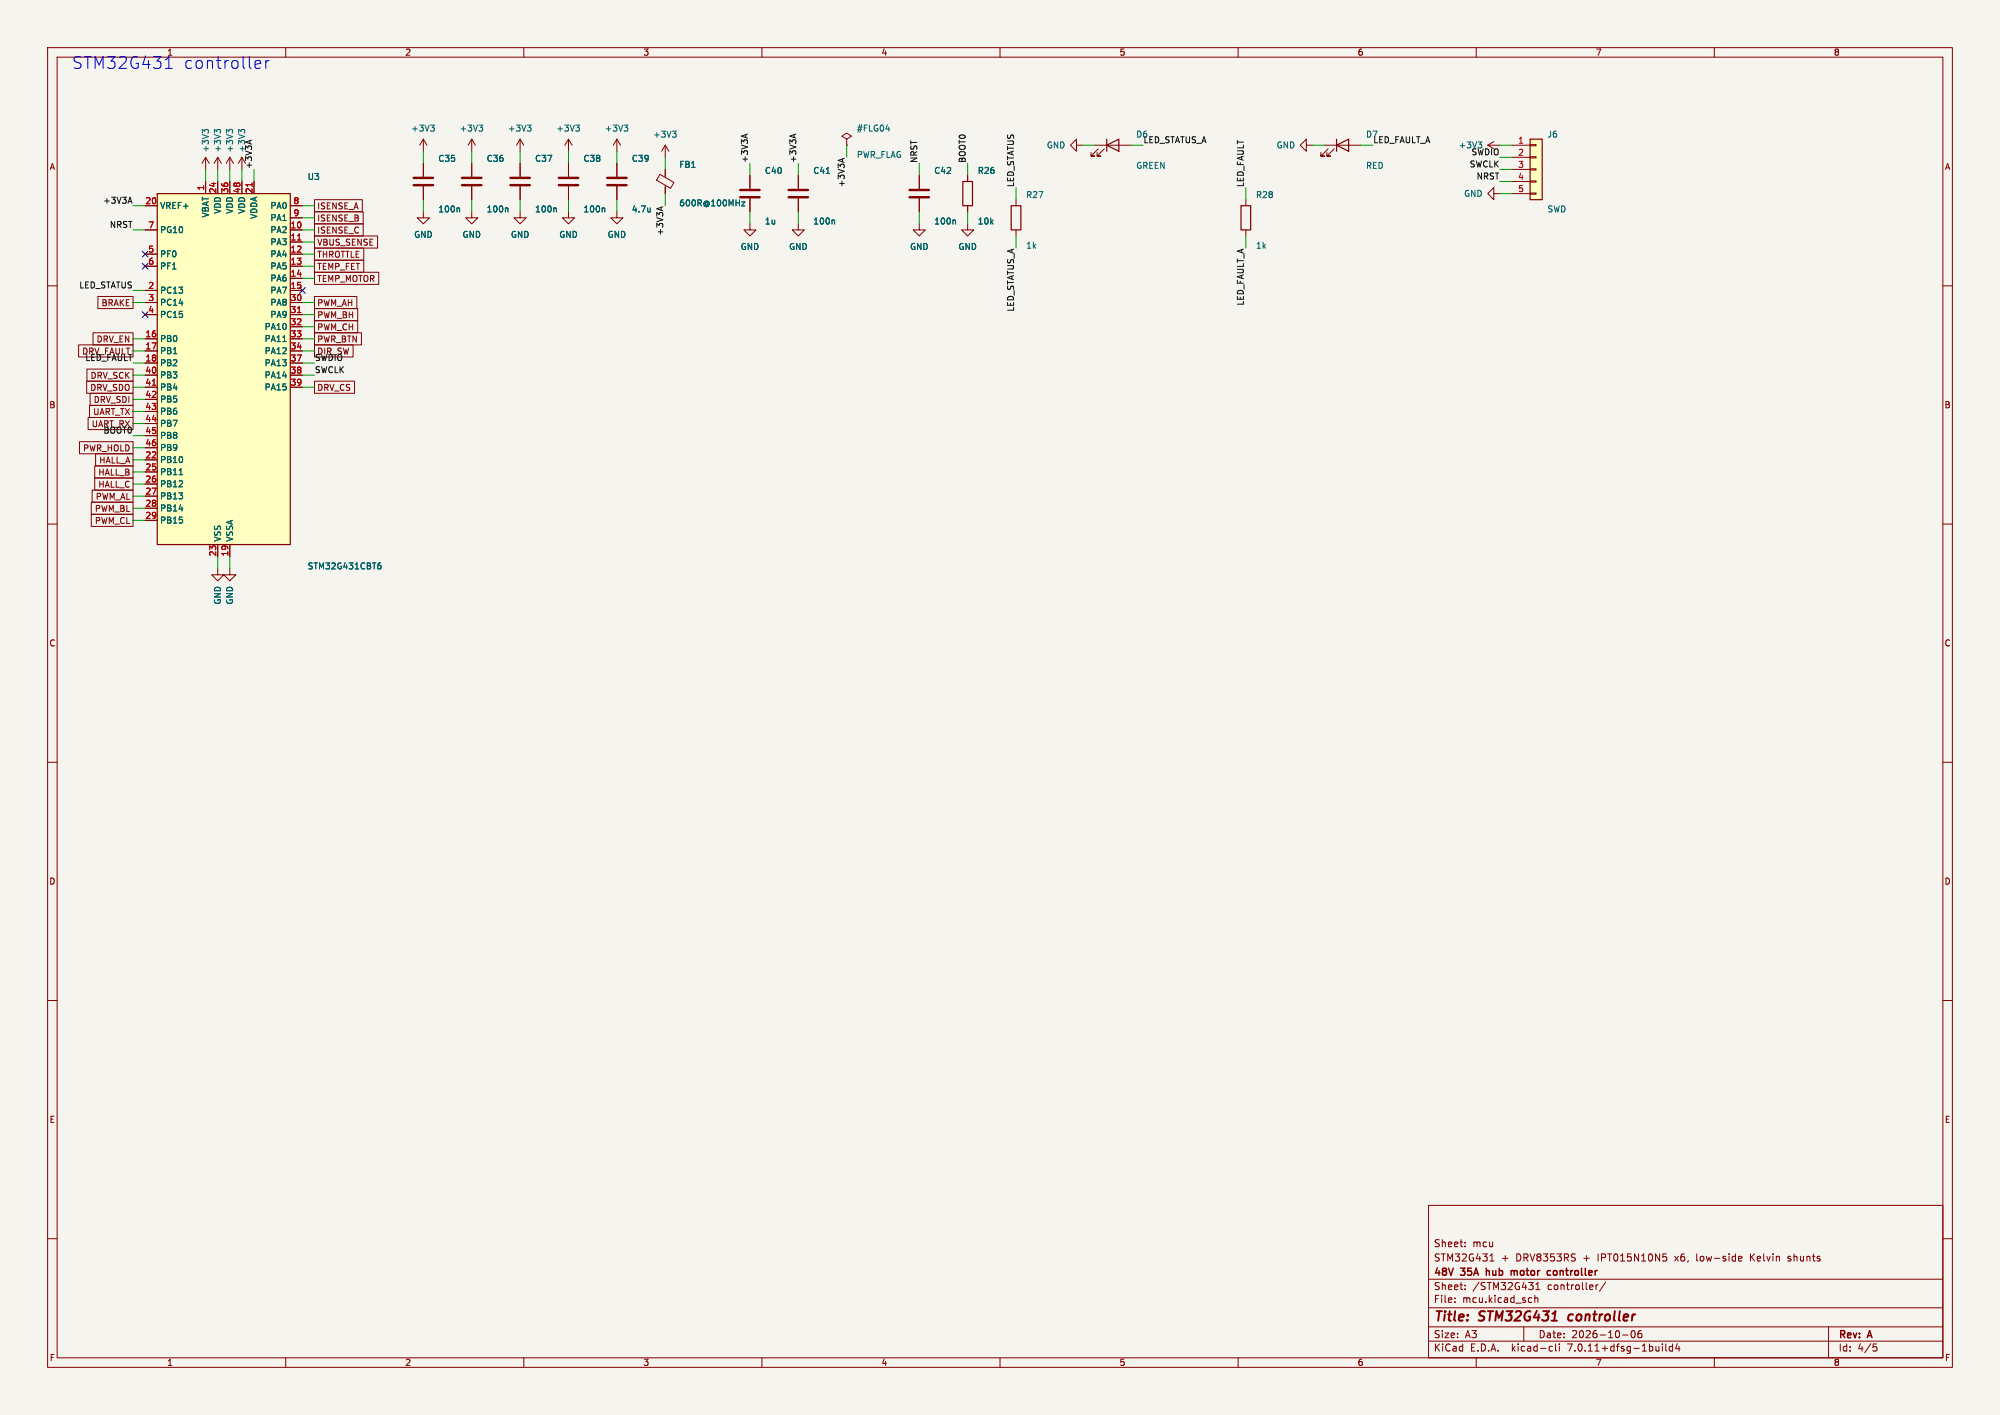
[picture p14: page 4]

1 PA2 10 PA3 11 PA4 12 PA5 13 PA6 14 PA7 15 PB0 16 PB1 17 PB2 18 VSSA 19 PC13 2 VREF+ 20 VDDA 21 PB10 22 VSS 23 VDD 24 PB11 25 PB12 26 PB13 27 PB14 28 PB15 29 PC14 3 PA8 30 PA9 31 PA10 32 PA11 33 PA12 34 VDD 36 PA13 37 PA14 38 PA15 39 PC15 4 PB3 40 PB4 41 PB5 42 PB6 43 PB7 44 PB8 45 PB9 46 VDD 48 PF0 5 PF1 6 PG10 7 PA0 8 PA1 9 C35

1 PA2 10 PA3 11 PA4 12 PA5 13 PA6 14 PA7 15 PB0 16 PB1 17 PB2 18 VSSA 19 PC13 2 VREF+ 20 VDDA 21 PB10 22 VSS 23 VDD 24 PB11 25 PB12 26 PB13 27 PB14 28 PB15 29 PC14 3 PA8 30 PA9 31 PA10 32 PA11 33 PA12 34 VDD 36 PA13 37 PA14 38 PA15 39 PC15 4 PB3 40 PB4 41 PB5 42 PB6 43 PB7 44 PB8 45 PB9 46 VDD 48 PF0 5 PF1 6 PG10 7 PA0 8 PA1 9 U3STM32G431CBT6 GND

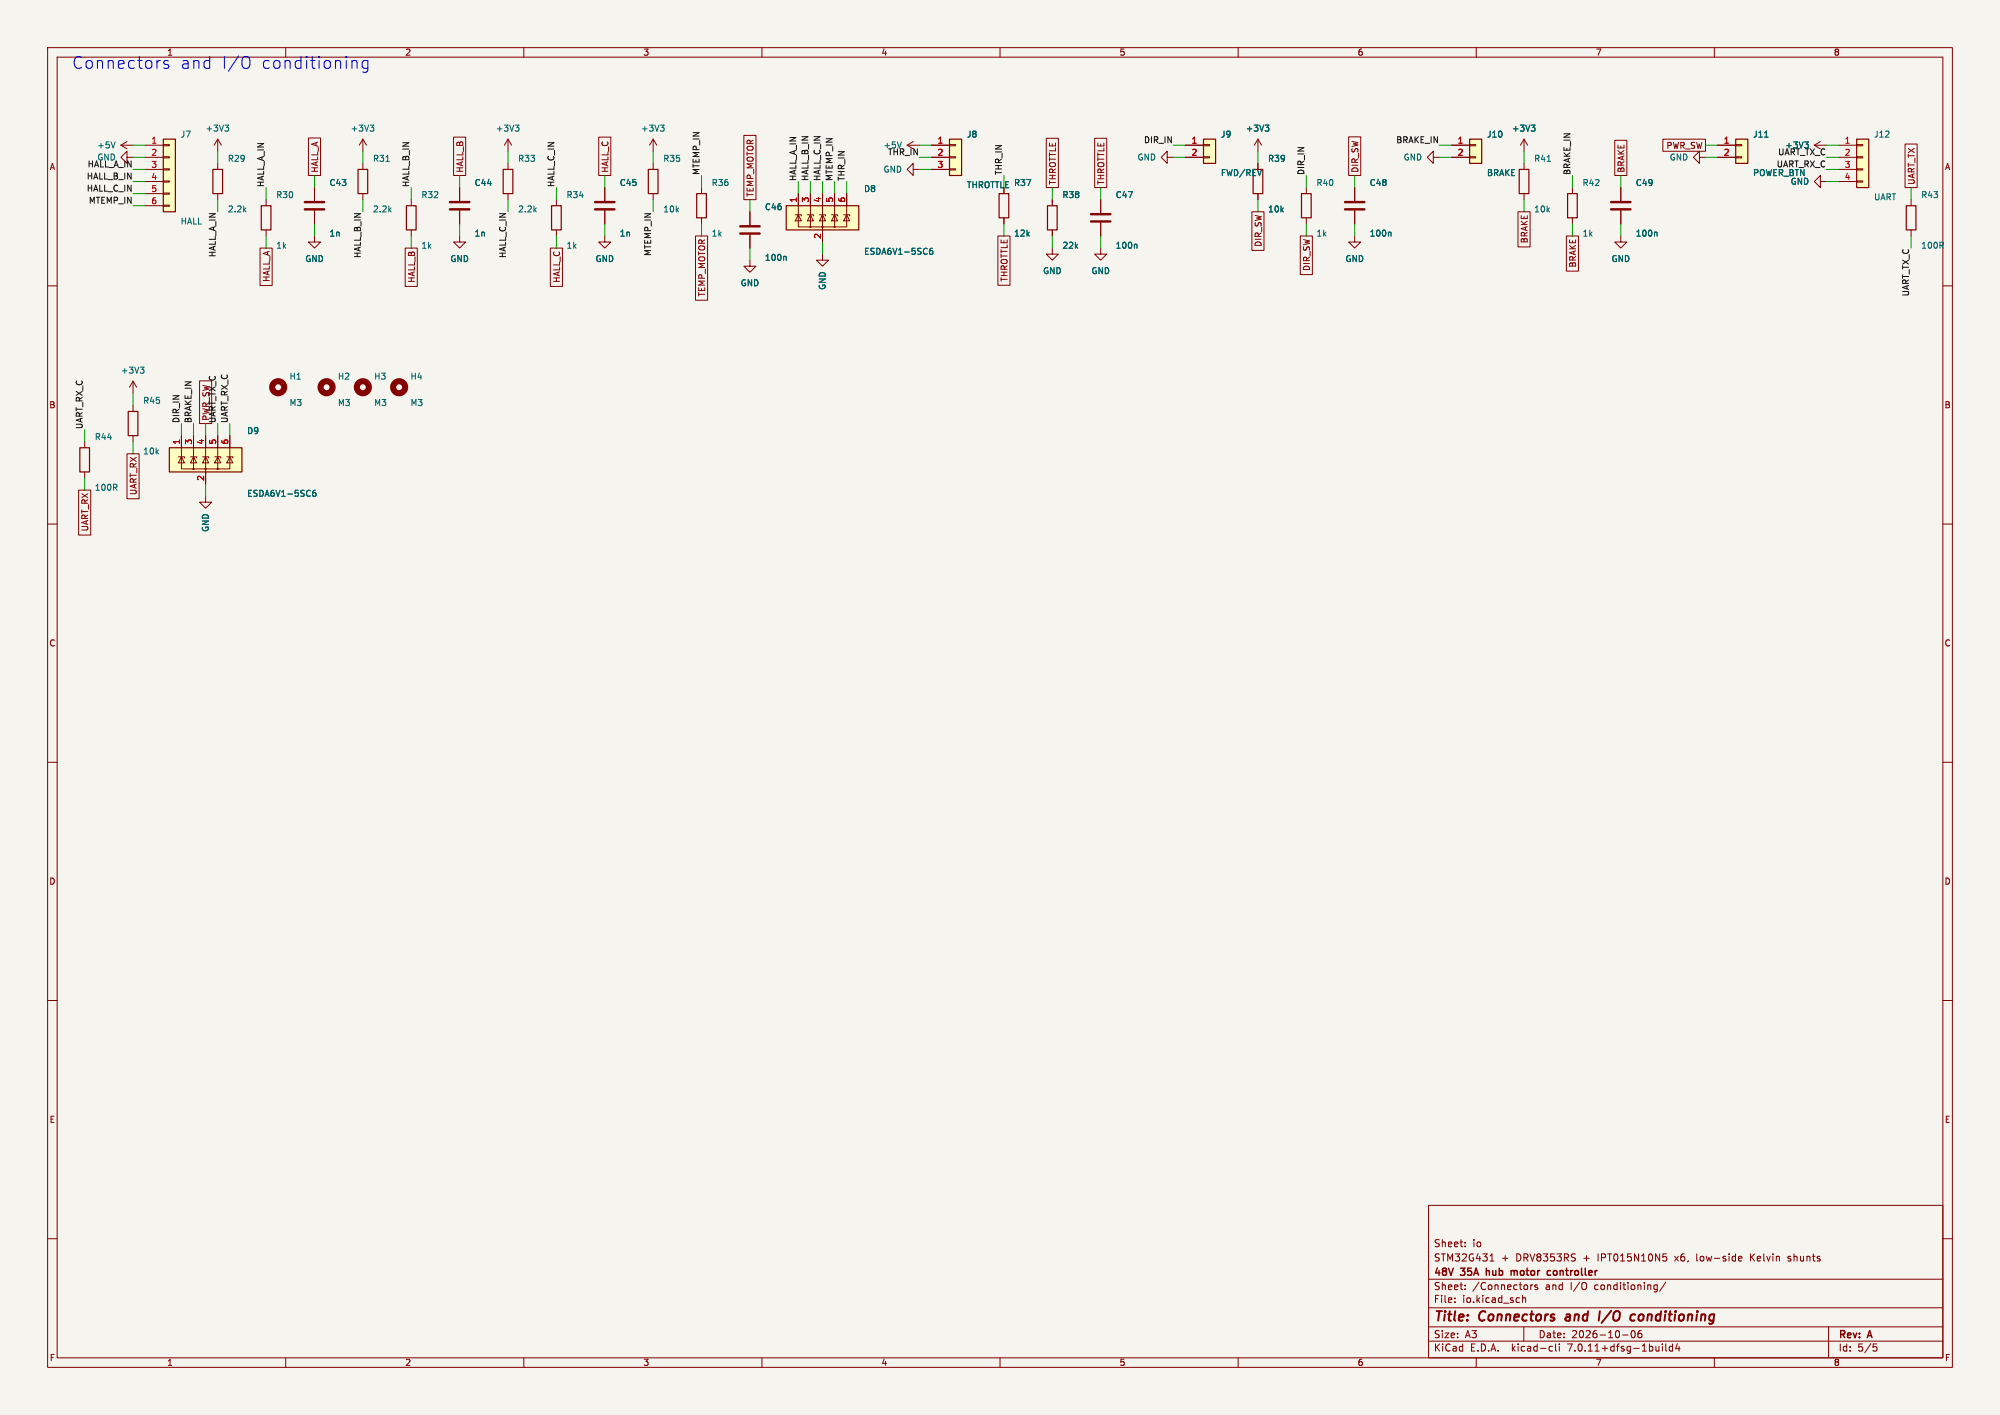
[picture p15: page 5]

6 D9ESDA6V1-5SC6 HALL_B UART_RX DIR_SW TEMP_MOTOR TEMP_MOTOR THROTTLE BRAKE PWR_SW HALL_B BRAKE BRAKE UART_TX HALL_C DIR_SW HALL_C HALL_A UART_RX THROTTLEPWR_SW THROTTLE HALL_A DIR_SW HALL_A_IN

Id: 5/5 Title: Connectors and I/O conditioning

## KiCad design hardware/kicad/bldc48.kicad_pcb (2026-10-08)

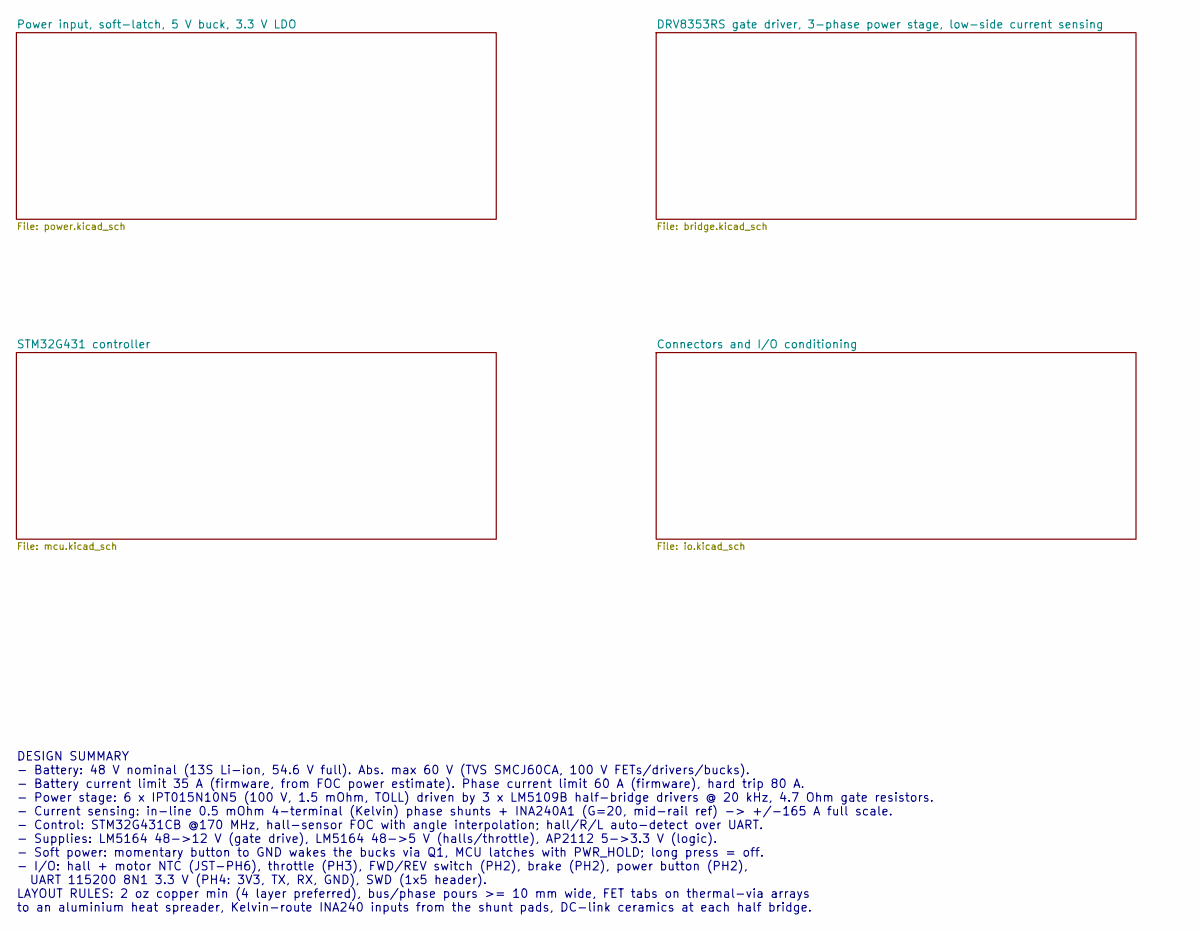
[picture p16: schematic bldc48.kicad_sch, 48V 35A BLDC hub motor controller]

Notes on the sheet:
DESIGN SUMMARY - Battery: 48 V nominal (13S Li-ion, 54.6 V full). Abs. max 60 V (TVS SMCJ60CA, 100 V FETs/drivers/bucks). - Battery current limit 35 A (firmware, from FOC power estimate). Phase current limit 60 A (firmware), hard trip 80 A. - Power stage: 6 x IPT015N10N5 (100 V, 1.5 mOhm, TOLL) dri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

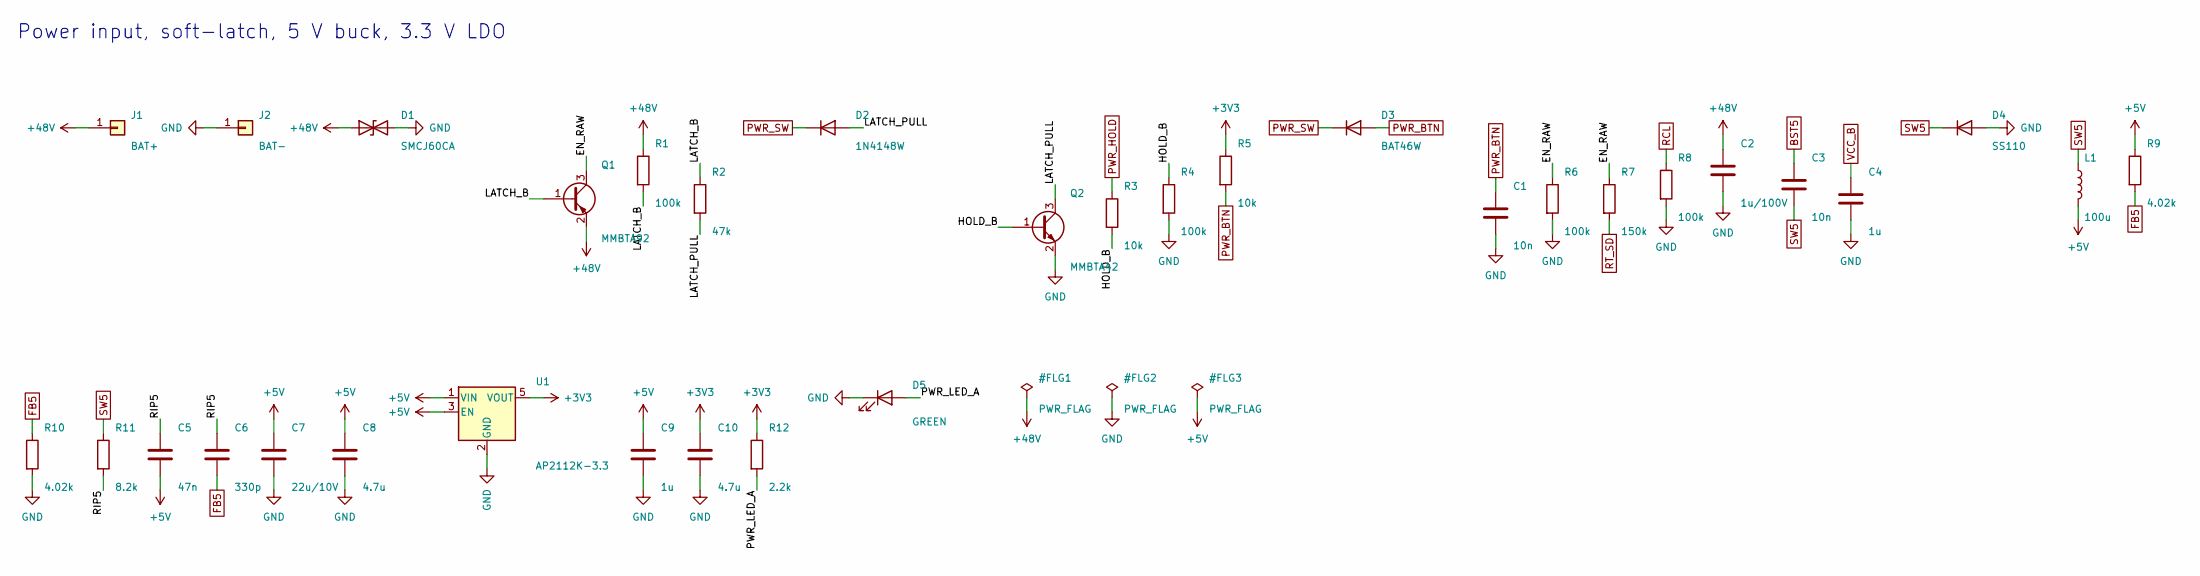
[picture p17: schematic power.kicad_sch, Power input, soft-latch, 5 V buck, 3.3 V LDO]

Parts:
C1, C3: 10n; C_0603_1608Metric
C2: 1u/100V; C_0805_2012Metric
C4, C9: 1u; C_0603_1608Metric
C5: 47n; C_0603_1608Metric
C6: 330p; C_0603_1608Metric
C7: 22u/10V; C_1210_3225Metric
C8, C10: 4.7u; C_0805_2012Metric
D1: SMCJ60CA; D_SMC
D2: 1N4148W; D_SOD-123
D3: BAT46W; D_SOD-123
D4: SS110; D_SMA; MPN 100 V 1 A Schottky, SMA (e.g. MDD SS110)
D5: GREEN; LED_0603_1608Metric
J1: BAT+; SolderWire_12AWG_D2.8mm_OD5.4mm; MPN 12 AWG wire, soldered
J2: BAT-; SolderWire_12AWG_D2.8mm_OD5.4mm; MPN 12 AWG wire, soldered
L1: 100u; L_Bourns_SRN6045TA; MPN Bourns SRN6045TA-101M or eq. (100 uH, I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
Q1: MMBTA92; SOT-23
Q2: MMBTA42; SOT-23
R1, R4, R6, R8: 100k; R_0603_1608Metric
R2: 47k; R_0603_1608Metric
R3, R5: 10k; R_0603_1608Metric
R7: 150k; R_0603_1608Metric
R9, R10: 4.02k; R_0603_1608Metric
R11: 8.2k; R_0603_1608Metric
R12: 2.2k; R_0603_1608Metric
U1: AP2112K-3.3; SOT-23-5

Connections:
+3V3: C10.1, R5.1, R12.1, U1.5 (VOUT); also elsewhere on the board
+5V: C5.2, C7.1, C8.1, C9.1, L1.2, R9.1, U1.1 (VIN), U1.3 (EN); also elsewhere on the board
+48V: C2.1, D1.1 (A1), J1.1, Q1.2 (E), R1.1; also elsewhere on the board
BST5: C3.1; also elsewhere on the board
EN_RAW: Q1.3 (C), R6.1, R7.1
FB5: C6.2, R9.2, R10.1; also elsewhere on the board
GND: C1.2, C2.2, C4.2, C7.2, C8.2, C9.2, C10.2, D1.2 (A2), D4.2 (A), D5.1 (K), J2.1, Q2.2 (E), R4.2, R6.2, R8.2, R10.2, U1.2 (GND); also elsewhere on the board
HOLD_B: Q2.1 (B), R3.2, R4.1
LATCH_B: Q1.1 (B), R1.2, R2.1
LATCH_PULL: D2.2 (A), Q2.3 (C), R2.2
PWR_BTN: C1.1, D3.2 (A), R5.2; also elsewhere on the board
PWR_HOLD: R3.1; also elsewhere on the board
PWR_LED_A: D5.2 (A), R12.2
PWR_SW: D2.1 (K), D3.1 (K); also elsewhere on the board
RCL: R8.1; also elsewhere on the board
RIP5: C5.1, C6.1, R11.2
RT_SD: R7.2; also elsewhere on the board
SW5: C3.2, D4.1 (K), L1.1, R11.1; also elsewhere on the board
VCC_B: C4.1; also elsewhere on the board

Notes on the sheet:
Power input, soft-latch, 5 V buck, 3.3 V LDO

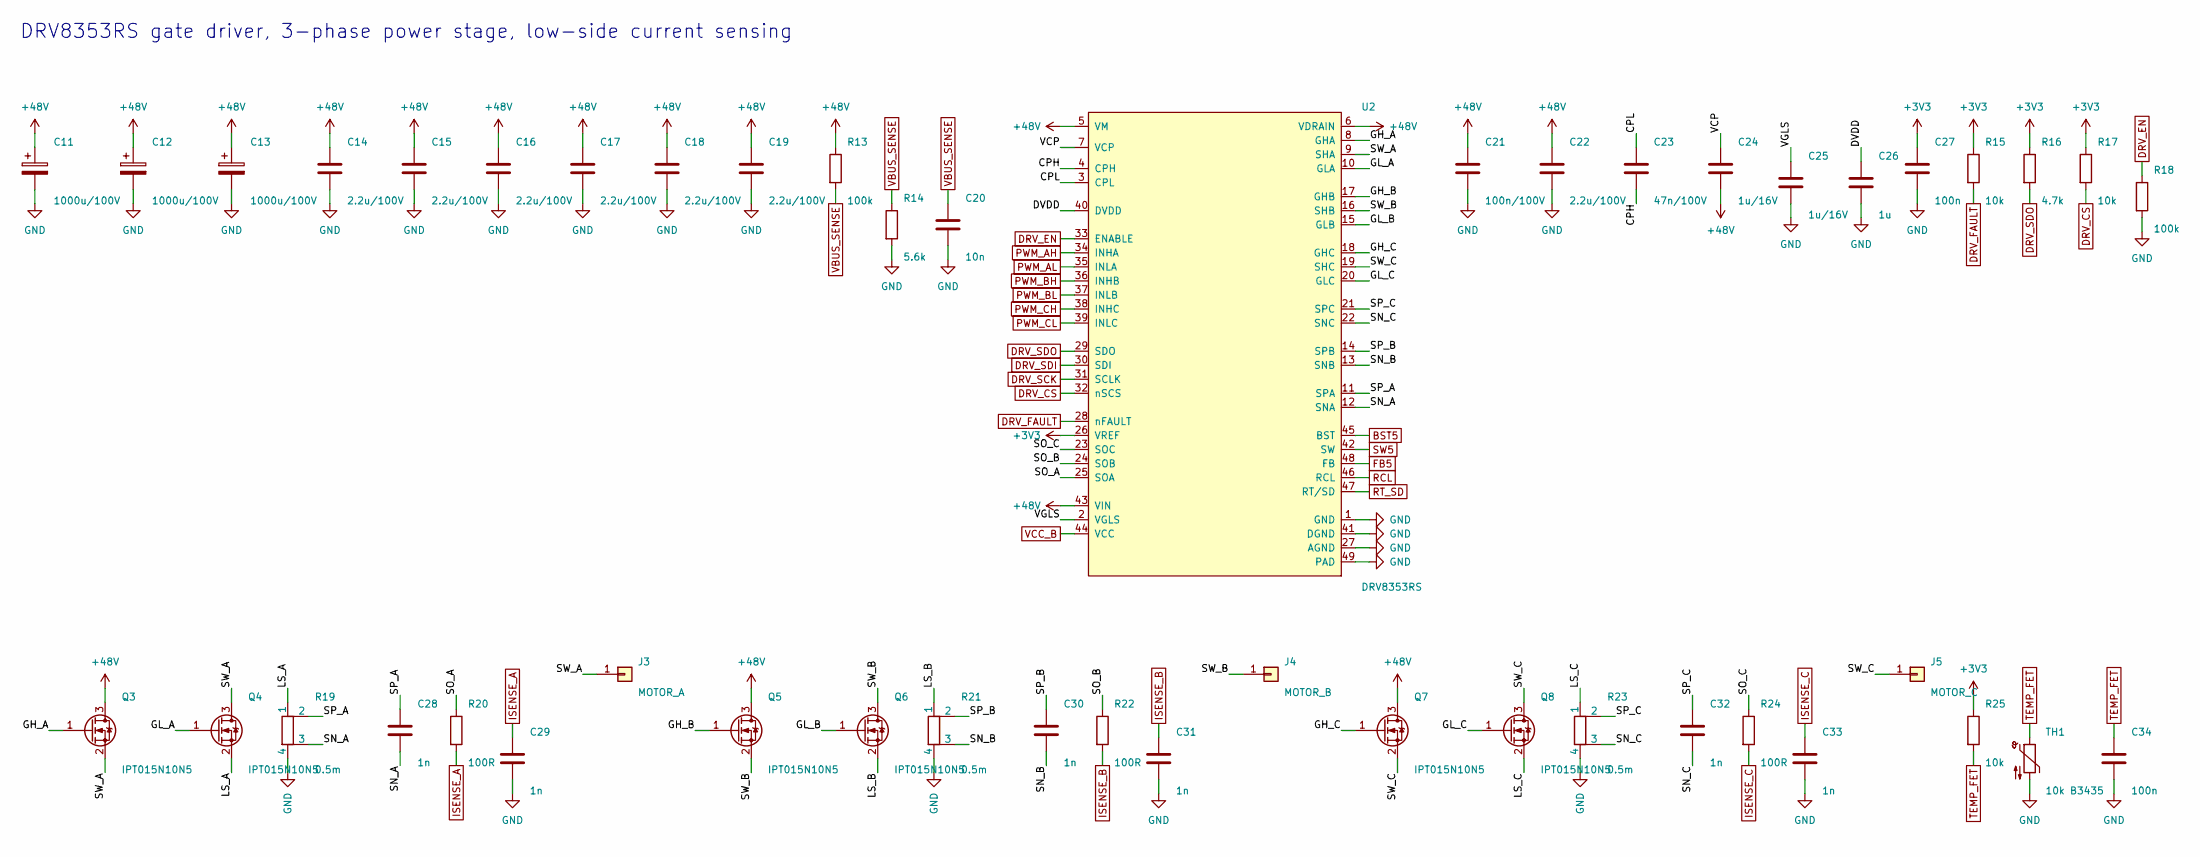
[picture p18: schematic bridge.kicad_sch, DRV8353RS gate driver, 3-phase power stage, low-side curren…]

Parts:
C11, C12, C13: 1000u/100V; CP_Radial_D18.0mm_P7.50mm; MPN Aishi ERS1KM102M35OT (LCSC C724666), 18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
C14, C15, C16, C17, C18, C19, C22: 2.2u/100V; C_1210_3225Metric
C20: 10n; C_0603_1608Metric
C21: 100n/100V; C_0805_2012Metric
C23: 47n/100V; C_0805_2012Metric
C24, C25: 1u/16V; C_0603_1608Metric
C26: 1u; C_0603_1608Metric
C27, C34: 100n; C_0603_1608Metric
C28, C29, C30, C31, C32, C33: 1n; C_0603_1608Metric
J3: MOTOR_A; SolderWire_12AWG_D2.8mm_OD5.4mm; MPN 12 AWG wire, soldered
J4: MOTOR_B; SolderWire_12AWG_D2.8mm_OD5.4mm; MPN 12 AWG wire, soldered
J5: MOTOR_C; SolderWire_12AWG_D2.8mm_OD5.4mm; MPN 12 AWG wire, soldered
Q3, Q4, Q5, Q6, Q7, Q8: IPT015N10N5; Infineon_PG-HSOF-8-1
R13, R18: 100k; R_0603_1608Metric
R14: 5.6k; R_0603_1608Metric
R15, R17, R25: 10k; R_0603_1608Metric
R16: 4.7k; R_0603_1608Metric
R19, R21, R23: 0.5m; R_Shunt_Isabellenhuette_BVR4026; MPN Bourns CSS4J-4026R-L500F (LCSC C2076423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
R20, R22, R24: 100R; R_0603_1608Metric
TH1: 10k B3435; R_0603_1608Metric; MPN Murata NCP18XH103F03RB (LCSC C13564)
U2: DRV8353RS; TI-RGZ-48-QFN; MPN TI DRV8353RSRGZR (LCSC C506246)

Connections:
+3V3: C27.1, R15.1, R16.1, R17.1, R25.1, U2.26 (VREF); also elsewhere on the board
+48V: C11.1, C12.1, C13.1, C14.1, C15.1, C16.1, C17.1, C18.1, C19.1, C21.1, C22.1, C24.2, Q3.3 (D), Q5.3 (D), Q7.3 (D), R13.1, U2.5 (VM), U2.6 (VDRAIN), U2.43 (VIN); also elsewhere on the board
BST5: U2.45 (BST); also elsewhere on the board
CPH: C23.2, U2.4 (CPH)
CPL: C23.1, U2.3 (CPL)
DRV_CS: R17.2, U2.32 (nSCS); also elsewhere on the board
DRV_EN: R18.1, U2.33 (ENABLE); also elsewhere on the board
DRV_FAULT: R15.2, U2.28 (nFAULT); also elsewhere on the board
DRV_SCK: U2.31 (SCLK); also elsewhere on the board
DRV_SDI: U2.30 (SDI); also elsewhere on the board
DRV_SDO: R16.2, U2.29 (SDO); also elsewhere on the board
DVDD: C26.1, U2.40 (DVDD)
FB5: U2.48 (FB); also elsewhere on the board
GH_A: Q3.1 (G), U2.8 (GHA)
GH_B: Q5.1 (G), U2.17 (GHB)
GH_C: Q7.1 (G), U2.18 (GHC)
GL_A: Q4.1 (G), U2.10 (GLA)
GL_B: Q6.1 (G), U2.15 (GLB)
GL_C: Q8.1 (G), U2.20 (GLC)
GND: C11.2, C12.2, C13.2, C14.2, C15.2, C16.2, C17.2, C18.2, C19.2, C20.2, C21.2, C22.2, C25.2, C26.2, C27.2, C29.2, C31.2, C33.2, C34.2, R14.2, R18.2, R19.4, R21.4, R23.4, TH1.2, U2.1 (GND), U2.27 (AGND), U2.41 (DGND), U2.49 (PAD); also elsewhere on the board
ISENSE_A: C29.1, R20.2; also elsewhere on the board
ISENSE_B: C31.1, R22.2; also elsewhere on the board
ISENSE_C: C33.1, R24.2; also elsewhere on the board
LS_A: Q4.2 (S), R19.1
LS_B: Q6.2 (S), R21.1
LS_C: Q8.2 (S), R23.1
PWM_AH: U2.34 (INHA); also elsewhere on the board
PWM_AL: U2.35 (INLA); also elsewhere on the board
PWM_BH: U2.36 (INHB); also elsewhere on the board
PWM_BL: U2.37 (INLB); also elsewhere on the board
PWM_CH: U2.38 (INHC); also elsewhere on the board
PWM_CL: U2.39 (INLC); also elsewhere on the board
RCL: U2.46 (RCL); also elsewhere on the board
RT_SD: U2.47 (RT/SD); also elsewhere on the board
SN_A: C28.2, R19.3, U2.12 (SNA)
SN_B: C30.2, R21.3, U2.13 (SNB)
SN_C: C32.2, R23.3, U2.22 (SNC)
SO_A: R20.1, U2.25 (SOA)
SO_B: R22.1, U2.24 (SOB)
SO_C: R24.1, U2.23 (SOC)
SP_A: C28.1, R19.2, U2.11 (SPA)
SP_B: C30.1, R21.2, U2.14 (SPB)
SP_C: C32.1, R23.2, U2.21 (SPC)
SW5: U2.42 (SW); also elsewhere on the board
SW_A: J3.1, Q3.2 (S), Q4.3 (D), U2.9 (SHA)
SW_B: J4.1, Q5.2 (S), Q6.3 (D), U2.16 (SHB)
SW_C: J5.1, Q7.2 (S), Q8.3 (D), U2.19 (SHC)
TEMP_FET: C34.1, R25.2, TH1.1; also elsewhere on the board
VBUS_SENSE: C20.1, R13.2, R14.1; also elsewhere on the board
VCC_B: U2.44 (VCC); also elsewhere on the board
VCP: C24.1, U2.7 (VCP)
VGLS: C25.1, U2.2 (VGLS)

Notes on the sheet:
DRV8353RS gate driver, 3-phase power stage, low-side current sensing

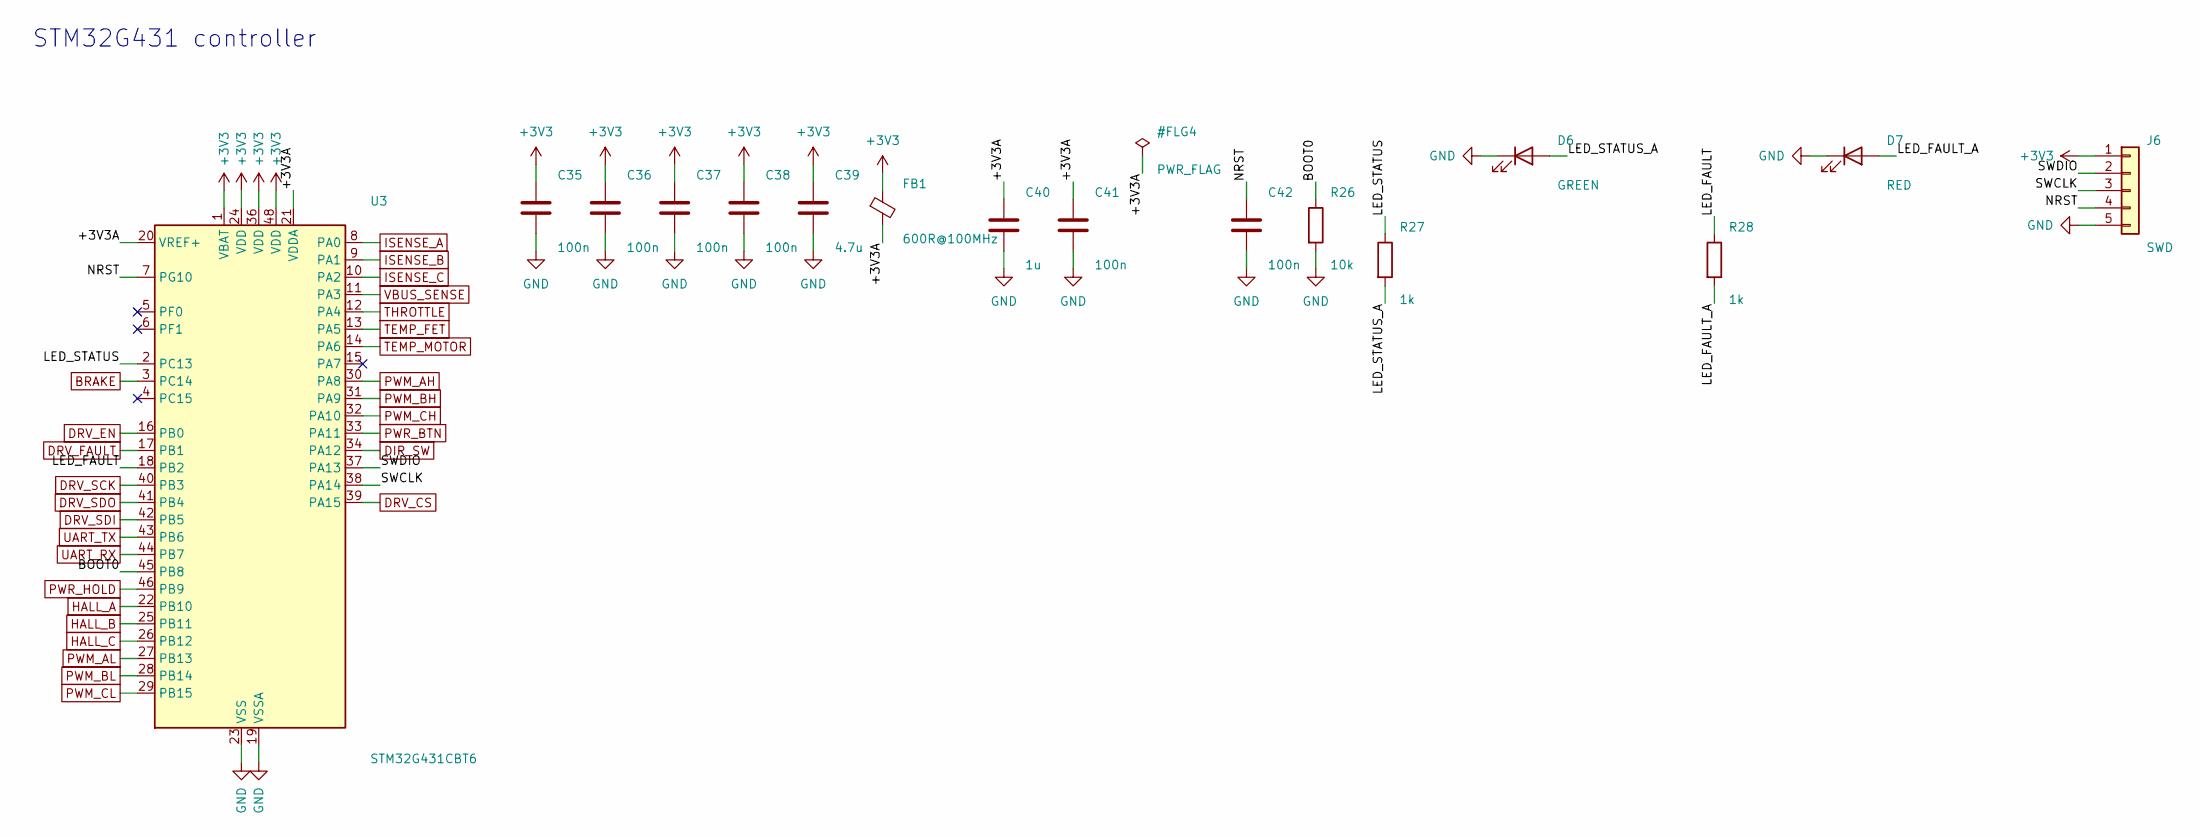
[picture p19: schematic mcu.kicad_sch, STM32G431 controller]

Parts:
C35, C36, C37, C38, C41, C42: 100n; C_0603_1608Metric
C39: 4.7u; C_0805_2012Metric
C40: 1u; C_0603_1608Metric
D6: GREEN; LED_0603_1608Metric
D7: RED; LED_0603_1608Metric
FB1: 600R@100MHz; L_0603_1608Metric
J6: SWD; JST_GH_BM05B-GHS-TBT_1x05-1MP_P1.25mm_Vertical; MPN JST BM05B-GHS-TBT (1.25 mm, latching)
R26: 10k; R_0603_1608Metric
R27, R28: 1k; R_0603_1608Metric
U3: STM32G431CBT6; LQFP-48_7x7mm_P0.5mm

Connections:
+3V3: C35.1, C36.1, C37.1, C38.1, C39.1, FB1.1, J6.1, U3.1 (VBAT), U3.24 (VDD), U3.36 (VDD), U3.48 (VDD); also elsewhere on the board
+3V3A: C40.1, C41.1, FB1.2, U3.20 (VREF+), U3.21 (VDDA)
BOOT0: R26.1, U3.45 (PB8)
BRAKE: U3.3 (PC14); also elsewhere on the board
DIR_SW: U3.34 (PA12); also elsewhere on the board
DRV_CS: U3.39 (PA15); also elsewhere on the board
DRV_EN: U3.16 (PB0); also elsewhere on the board
DRV_FAULT: U3.17 (PB1); also elsewhere on the board
DRV_SCK: U3.40 (PB3); also elsewhere on the board
DRV_SDI: U3.42 (PB5); also elsewhere on the board
DRV_SDO: U3.41 (PB4); also elsewhere on the board
GND: C35.2, C36.2, C37.2, C38.2, C39.2, C40.2, C41.2, C42.2, D6.1 (K), D7.1 (K), J6.5, R26.2, U3.19 (VSSA), U3.23 (VSS), U3.35 (VSS), U3.47 (VSS); also elsewhere on the board
HALL_A: U3.22 (PB10); also elsewhere on the board
HALL_B: U3.25 (PB11); also elsewhere on the board
HALL_C: U3.26 (PB12); also elsewhere on the board
ISENSE_A: U3.8 (PA0); also elsewhere on the board
ISENSE_B: U3.9 (PA1); also elsewhere on the board
ISENSE_C: U3.10 (PA2); also elsewhere on the board
LED_FAULT: R28.1, U3.18 (PB2)
LED_FAULT_A: D7.2 (A), R28.2
LED_STATUS: R27.1, U3.2 (PC13)
LED_STATUS_A: D6.2 (A), R27.2
NRST: C42.1, J6.4, U3.7 (PG10)
PWM_AH: U3.30 (PA8); also elsewhere on the board
PWM_AL: U3.27 (PB13); also elsewhere on the board
PWM_BH: U3.31 (PA9); also elsewhere on the board
PWM_BL: U3.28 (PB14); also elsewhere on the board
PWM_CH: U3.32 (PA10); also elsewhere on the board
PWM_CL: U3.29 (PB15); also elsewhere on the board
PWR_BTN: U3.33 (PA11); also elsewhere on the board
PWR_HOLD: U3.46 (PB9); also elsewhere on the board
SWCLK: J6.3, U3.38 (PA14)
SWDIO: J6.2, U3.37 (PA13)
TEMP_FET: U3.13 (PA5); also elsewhere on the board
TEMP_MOTOR: U3.14 (PA6); also elsewhere on the board
THROTTLE: U3.12 (PA4); also elsewhere on the board
UART_RX: U3.44 (PB7); also elsewhere on the board
UART_TX: U3.43 (PB6); also elsewhere on the board
VBUS_SENSE: U3.11 (PA3); also elsewhere on the board

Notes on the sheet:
STM32G431 controller

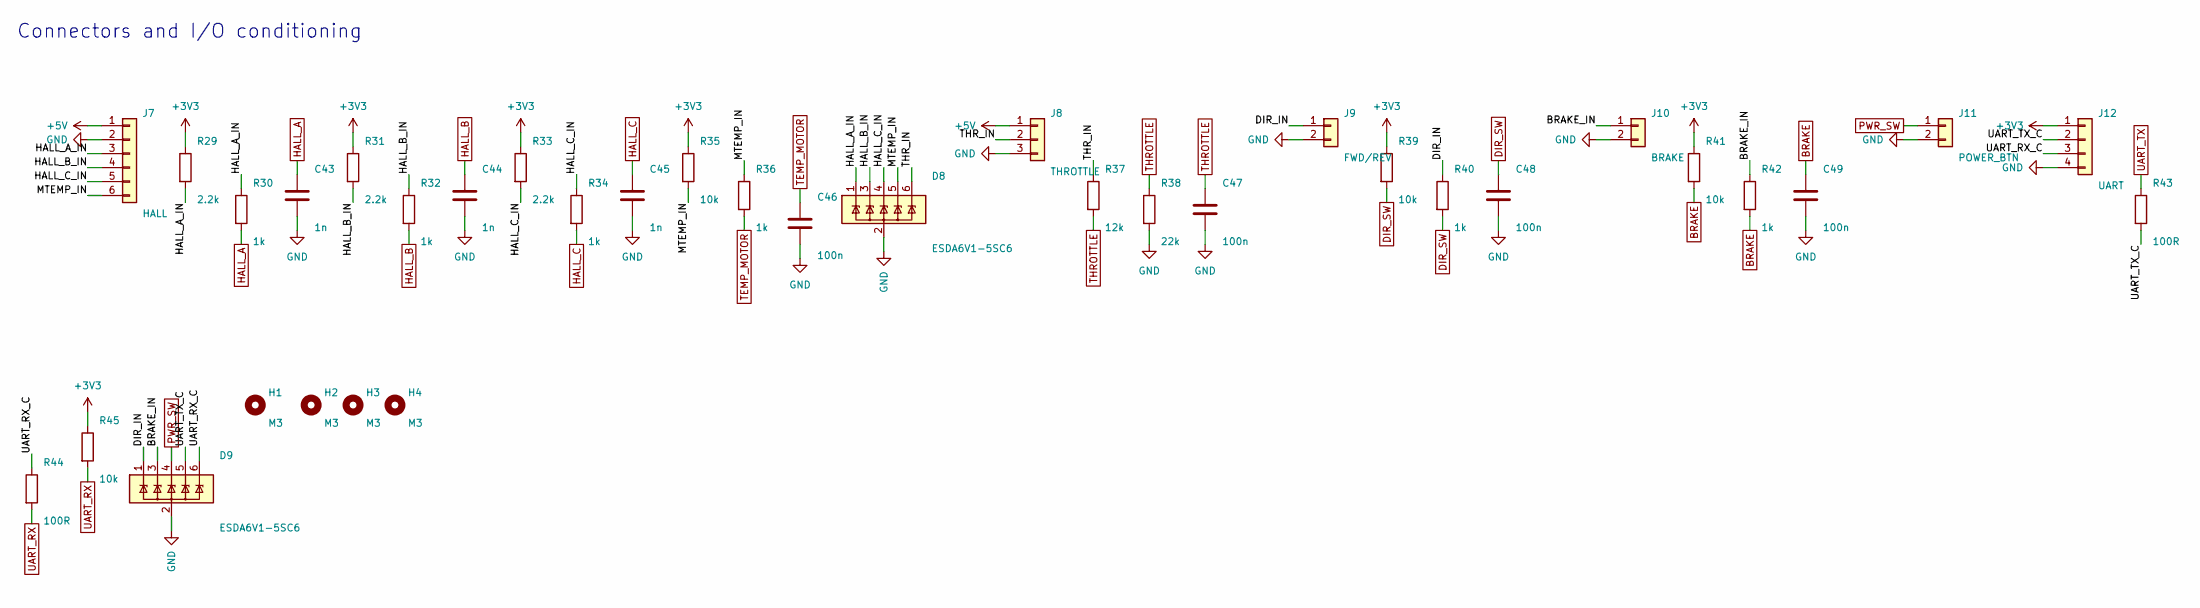
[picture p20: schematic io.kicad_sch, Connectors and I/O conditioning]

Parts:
C43, C44, C45: 1n; C_0603_1608Metric
C46, C47, C48, C49: 100n; C_0603_1608Metric
D8, D9: ESDA6V1-5SC6; SOT-23-6
H1, H2, H3, H4: M3; MountingHole_3.2mm_M3
J7: HALL; JST_GH_BM06B-GHS-TBT_1x06-1MP_P1.25mm_Vertical; MPN JST BM06B-GHS-TBT (1.25 mm, latching)
J8: THROTTLE; JST_GH_BM03B-GHS-TBT_1x03-1MP_P1.25mm_Vertical; MPN JST BM03B-GHS-TBT (1.25 mm, latching)
J9: FWD/REV; JST_GH_BM02B-GHS-TBT_1x02-1MP_P1.25mm_Vertical; MPN JST BM02B-GHS-TBT (1.25 mm, latching)
J10: BRAKE; JST_GH_BM02B-GHS-TBT_1x02-1MP_P1.25mm_Vertical; MPN JST BM02B-GHS-TBT (1.25 mm, latching)
J11: POWER_BTN; JST_GH_BM02B-GHS-TBT_1x02-1MP_P1.25mm_Vertical; MPN JST BM02B-GHS-TBT (1.25 mm, latching)
J12: UART; JST_GH_BM04B-GHS-TBT_1x04-1MP_P1.25mm_Vertical; MPN JST BM04B-GHS-TBT (1.25 mm, latching)
R29, R31, R33: 2.2k; R_0603_1608Metric
R30, R32, R34, R36, R40, R42: 1k; R_0603_1608Metric
R35, R39, R41, R45: 10k; R_0603_1608Metric
R37: 12k; R_0603_1608Metric
R38: 22k; R_0603_1608Metric
R43, R44: 100R; R_0603_1608Metric

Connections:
+3V3: J12.1, R29.1, R31.1, R33.1, R35.1, R39.1, R41.1, R45.1; also elsewhere on the board
+5V: J7.1, J8.1; also elsewhere on the board
BRAKE: C49.1, R41.2, R42.2; also elsewhere on the board
BRAKE_IN: D9.3 (IO2), J10.1, R42.1
DIR_IN: D9.1 (IO1), J9.1, R40.1
DIR_SW: C48.1, R39.2, R40.2; also elsewhere on the board
GND: C43.2, C44.2, C45.2, C46.2, C47.2, C48.2, C49.2, D8.2 (GND), D9.2 (GND), J7.2, J8.3, J9.2, J10.2, J11.2, J12.4, R38.2; also elsewhere on the board
HALL_A: C43.1, R30.2; also elsewhere on the board
HALL_A_IN: D8.1 (IO1), J7.3, R29.2, R30.1
HALL_B: C44.1, R32.2; also elsewhere on the board
HALL_B_IN: D8.3 (IO2), J7.4, R31.2, R32.1
HALL_C: C45.1, R34.2; also elsewhere on the board
HALL_C_IN: D8.4 (IO3), J7.5, R33.2, R34.1
MTEMP_IN: D8.5 (IO4), J7.6, R35.2, R36.1
PWR_SW: D9.4 (IO3), J11.1; also elsewhere on the board
TEMP_MOTOR: C46.1, R36.2; also elsewhere on the board
THROTTLE: C47.1, R37.2, R38.1; also elsewhere on the board
THR_IN: D8.6 (IO5), J8.2, R37.1
UART_RX: R44.2, R45.2; also elsewhere on the board
UART_RX_C: D9.6 (IO5), J12.3, R44.1
UART_TX: R43.1; also elsewhere on the board
UART_TX_C: D9.5 (IO4), J12.2, R43.2

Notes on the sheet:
Connectors and I/O conditioning

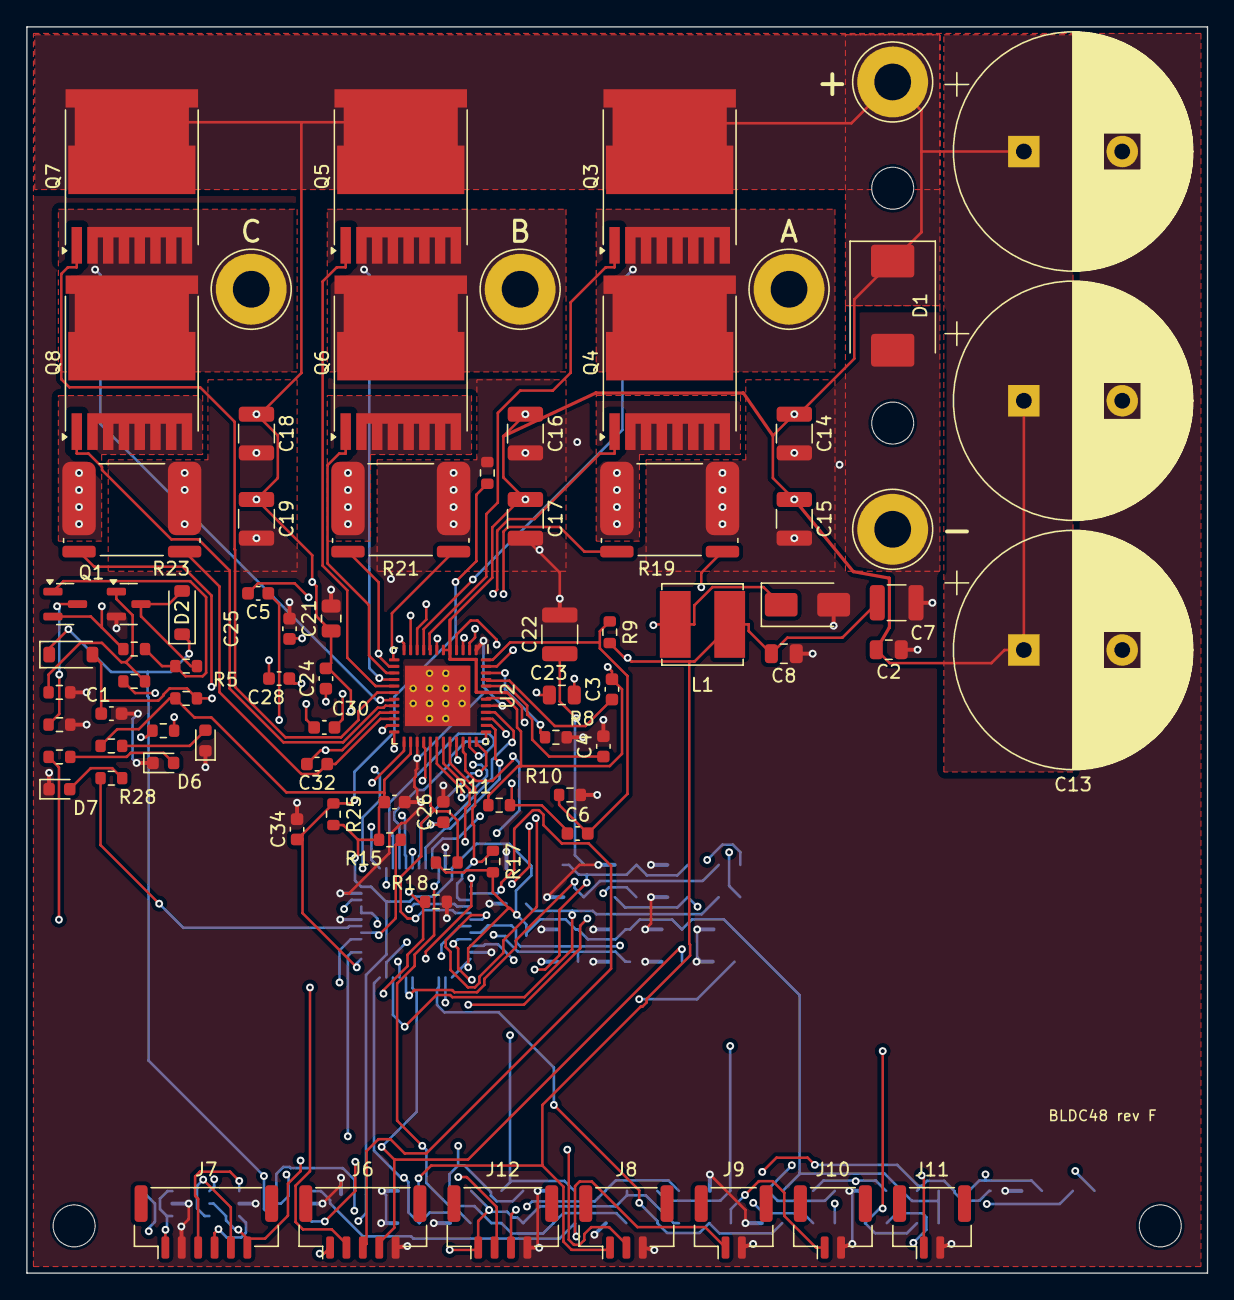
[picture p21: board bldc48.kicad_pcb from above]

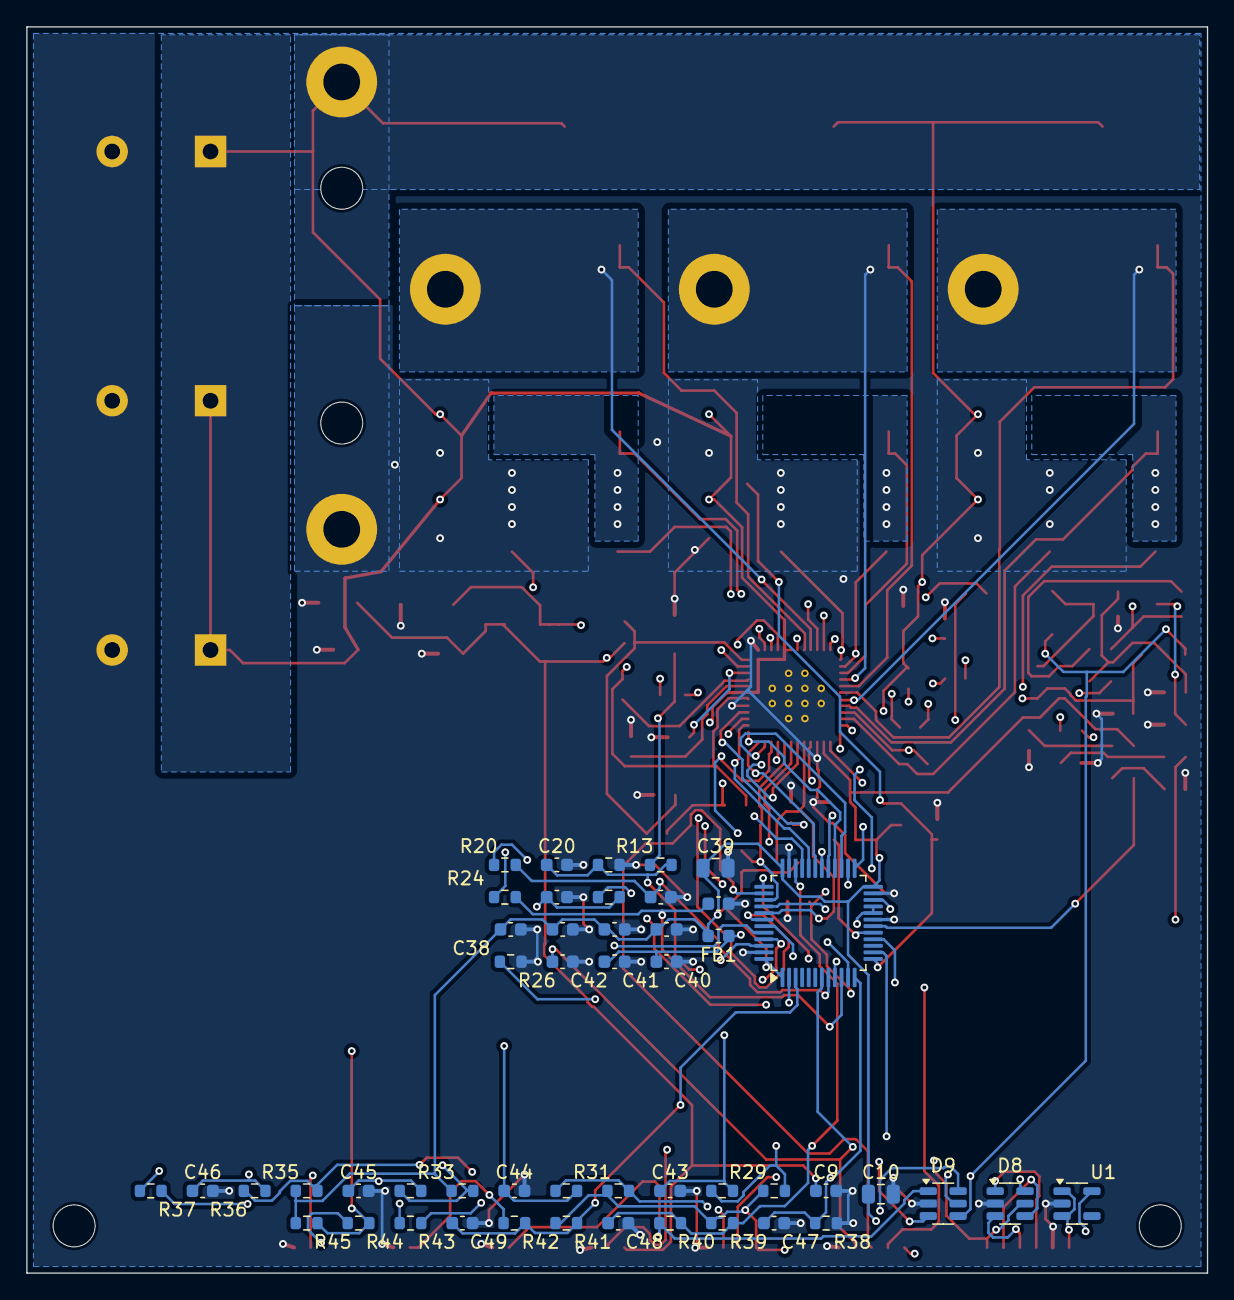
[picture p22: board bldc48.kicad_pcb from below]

Board: 4 copper layers, 90.0 x 95.0 mm, 133 parts (49 on the bottom side), 89 nets.

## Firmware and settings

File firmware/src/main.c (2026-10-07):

/*
 * 48 V / 35 A hall-sensored hub motor controller - main loop.
 *
 * Power button behaviour (momentary switch to GND):
 *   press          -> board powers up, firmware latches PWR_HOLD
 *   hold 2 s       -> motor stops, releases PWR_HOLD when the button is let go
 * Boot shortcut: hold BRAKE + full throttle for 3 s after power-up with the
 * wheel lifted to run auto-detect without a UART cable (saves automatically).
 */
#include <math.h>

#include "cli.h"
#include "config.h"
#include "drv8353.h"
#include "hall.h"
#include "hw.h"
#include "motor.h"

#define LONG_PRESS_MS 2000u

static void leds(uint32_t now)
{
    /* green: slow blink idle, solid running, fast blink detecting
       red  : fault code = number of blinks (lowest set fault bit + 1) */
    int on;
    switch (m.state) {
    case ST_RUN:
        on = 1;
        break;
    case ST_DET_R:
    case ST_DET_L:
    case ST_DET_HALL:
        on = (now / 100) & 1;
        break;
    default:
        on = (now % 1000) < 100;
        break;
    }
    led_ok(on);

    uint32_t f = m.faults & ~FLT_UNDERVOLTAGE;
    if (!f) {
        led_fault(m.faults & FLT_UNDERVOLTAGE ? (now % 2000) < 100 : 0);
        return;
    }
    int code = 0;
    while (!(f & 1u)) {
        f >>= 1;
        code++;
    }
    code++;
    uint32_t t = now % (uint32_t)(code * 400 + 1500);
    led_fault(t < (uint32_t)code * 400 && (t % 400) < 200);
}

static void shutdown(void)
{
    motor_shutdown();
    drv_sleep();
    cli_printf(">shutting down\r\n");
    while (btn_pressed()) {           /* releasing the hold while pressed does nothing */
        iwdg_kick();
        led_ok(0);
        led_fault((millis() / 50) & 1);
    }
    delay_ms(50);
    power_hold(0);
    /* if still powered (e.g. via SWD) wait for another press and restart */
    uint32_t t0 = millis();
    for (;;) {
        iwdg_kick();
        led_fault(0);
        if (millis() - t0 > 500 && btn_pressed())
            NVIC_SystemReset();
    }
}

int main(void)
{
    hw_early_hold();
    hw_init();
    int drv_ok = drv_init() == 0;            /* wake + configure the gate driver */
    int loaded = config_load();
    hall_init();
    motor_init();
    cli_init();
    if (!loaded)
        cli_printf(">no saved config, using defaults\r\n");
    if (!drv_ok) {                           /* default CSA gain would read 4x low */
        motor_driver_failed();
        cli_printf(">DRV8353 did not read back its settings (SPI?)\r\n");
    }
    iwdg_start();

    uint32_t last_ms = millis(), btn_t0 = 0, last_isr = 0, idle_since = millis();
    uint32_t combo_t0 = 0;
    int btn_armed = 0, combo_used = 0, combo_save = 0;

    for (;;) {
        uint32_t now = millis();

        /* watchdog only if the control interrupt is alive */
        if (m.isr_count != last_isr) {
            last_isr = m.isr_count;
            iwdg_kick();
        }

        if (now != last_ms) {
            last_ms = now;
            motor_slow(now);
            leds(now);

            /* power button: ignore the press that switched us on */
            if (!btn_pressed()) {
                btn_armed = 1;
                btn_t0 = 0;
            } else if (btn_armed) {
                if (!btn_t0)
                    btn_t0 = now;
                else if (now - btn_t0 > LONG_PRESS_MS)
                    shutdown();
            }
            if (cli_shutdown_req)
                shutdown();

            /* auto power-off */
            if (m.state != ST_IDLE || m.omega_e != 0.0f)
                idle_since = now;
            if (cfg.auto_off_min && now - idle_since > cfg.auto_off_min * 60000u)
                shutdown();

            /* brake + full throttle at power-up -> detect */
            if (!combo_used && now < 10000) {
                if (brake_on() && m.thr_v > cfg.thr_max_v - 0.3f && m.thr_v < cfg.thr_fault_hi) {
                    if (!combo_t0)
                        combo_t0 = now;
                    if (now - combo_t0 > 3000) {
                        combo_used = 1;
                        cli_printf(">release throttle to start detect\r\n");
                    }
                } else {
                    combo_t0 = 0;
                }
            }
            if (combo_used == 1 && m.thr_pct == 0.0f) {
                motor_clear_faults();
                if (motor_detect(0) == 0) {
                    combo_used = 2;
                    combo_save = 1;
                }
            }
            if (combo_save && m.state != ST_DET_R && m.state != ST_DET_L &&
                m.state != ST_DET_HALL && motor_detect_msg()) {
                combo_save = 0;
                cli_printf(">%s\r\n", motor_detect_msg());
                if (cfg.hall_valid && !(m.faults & FLT_DETECT))
                    cli_printf(config_save() ? ">ERR save failed\r\n" : ">OK saved\r\n");
            }
        }
        cli_poll(now);
    }
}

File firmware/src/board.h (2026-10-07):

/*
 * Board definition: pin map and analog scaling.  Must match
 * hardware/tools/circuit.py (the schematic is generated from that file).
 */
#ifndef BOARD_H
#define BOARD_H

#include "stm32g4xx.h"

#define SYSCLK_HZ        170000000u
#define PWM_HZ           20000u
#define PWM_ARR          (SYSCLK_HZ / (2u * PWM_HZ))     /* center aligned: 4250 */
#define CTRL_DT          (1.0f / PWM_HZ)
#define DEADTIME_TICKS   68u                             /* 68 * 5.88 ns = 400 ns */

/* ---- GPIO --------------------------------------------------------------- */
/* TIM1 PWM: PA8/PA9/PA10 = CH1..3 (AF6), PB13/PB14 = CH1N/CH2N (AF6), PB15 = CH3N (AF4)
 *           -> DRV8353RS INHx / INLx (6x PWM mode)                                    */
/* ADC1: PA0 IN1 = I_A, PA2 IN3 = I_C, PA3 IN4 = VBUS                                  */
/* ADC2: PA1 IN2 = I_B, PA4 IN17 = THROTTLE, PA5 IN13 = TEMP_FET, PA6 IN3 = TEMP_MOTOR */
/*       (I_A and I_B convert at the same time on the two ADCs)                        */
/* SPI1 (AF5): PB3 SCK, PB4 MISO (DRV SDO), PB5 MOSI (DRV SDI); PA15 nSCS (GPIO)       */
#define HALL_PORT        GPIOB
#define HALL_A_PIN       10u
#define HALL_B_PIN       11u
#define HALL_C_PIN       12u
/* USART1: PB6 TX, PB7 RX (AF7) */
#define BTN_PORT         GPIOA      /* PA11: power button sense, low = pressed */
#define BTN_PIN          11u
#define DIR_PORT         GPIOA      /* PA12: FWD/REV switch, low = reverse     */
#define DIR_PIN          12u
#define BRAKE_PORT       GPIOC      /* PC14: brake switch, low = braking       */
#define BRAKE_PIN        14u
#define DRV_CS_PORT      GPIOA      /* PA15: DRV8353 nSCS                      */
#define DRV_CS_PIN       15u
#define DRV_EN_PORT      GPIOB      /* PB0: DRV8353 ENABLE, high = awake       */
#define DRV_EN_PIN       0u
#define DRV_FLT_PORT     GPIOB      /* PB1: DRV8353 nFAULT, low = fault        */
#define DRV_FLT_PIN      1u
#define HOLD_PORT        GPIOB      /* PB9: power latch hold, high = stay on   */
#define HOLD_PIN         9u
#define LED_OK_PORT      GPIOC      /* PC13: green status LED                  */
#define LED_OK_PIN       13u
#define LED_FLT_PORT     GPIOB      /* PB2: red fault LED                      */
#define LED_FLT_PIN      2u

/* ---- Analog scaling ----------------------------------------------------- */
#define VREF             3.3f
#define ADC_FS           4096.0f
#define SHUNT_OHM        0.0005f                              /* low-side Kelvin shunts */
#define CSA_GAIN         20.0f                                /* DRV8353 CSA, set over SPI */
/* Low-side shunts only see a phase current while its low-side FET conducts,
 * i.e. around the PWM counter peak.  Above this duty the window is too short
 * (CSA settling + dead time), so that phase is rebuilt from the other two. */
#define DUTY_MEAS_MAX    0.90f
#define DUTY_MAX         0.97f      /* charge pump: 100 % allowed; keep a margin */
#define ADC_TRIG_LEAD    40u        /* TIM1 ticks before the peak (235 ns)       */
#define AMPS_PER_COUNT   (VREF / ADC_FS / (CSA_GAIN * SHUNT_OHM))   /* 0.0806 A */
#define VBUS_DIV         ((100.0f + 5.6f) / 5.6f)
#define VOLTS_PER_COUNT  (VREF / ADC_FS * VBUS_DIV)            /* 0.0152 V */
#define THR_DIV          ((12.0f + 22.0f) / 22.0f)
#define NTC_PULLUP_OHM   10000.0f
#define NTC_FET_BETA     3435.0f
#define NTC_R25          10000.0f

#define HARD_TRIP_AMPS   80.0f       /* instantaneous phase current trip */
#define ADC_FULLSCALE_A  (2048.0f * AMPS_PER_COUNT)         /* +/-165 A */

/* The hard trip must sit well inside what the current sense can report,
   otherwise a saturated ADC reading never reaches it. */
_Static_assert(HARD_TRIP_AMPS < 0.9f * (2048.0f * 3.3f / 4096.0f / (CSA_GAIN * SHUNT_OHM)),
               "overcurrent trip above current-sense full scale");

#endif

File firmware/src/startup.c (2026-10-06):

/* Minimal Cortex-M4F startup for STM32G431 (vector table + reset handler). */
#include <stdint.h>

#include "stm32g4xx.h"

extern uint32_t _sidata, _sdata, _edata, _sbss, _ebss, _estack;
extern int main(void);
extern void __libc_init_array(void);

void Reset_Handler(void);
void Default_Handler(void);

#define WEAK __attribute__((weak, alias("Default_Handler")))
void NMI_Handler(void) WEAK;
void HardFault_Handler(void) WEAK;
void MemManage_Handler(void) WEAK;
void BusFault_Handler(void) WEAK;
void UsageFault_Handler(void) WEAK;
void SVC_Handler(void) WEAK;
void DebugMon_Handler(void) WEAK;
void PendSV_Handler(void) WEAK;
void SysTick_Handler(void) WEAK;
void ADC1_2_IRQHandler(void) WEAK;
void EXTI15_10_IRQHandler(void) WEAK;
void USART1_IRQHandler(void) WEAK;

/* 102 device interrupts on STM32G431; unused ones go to Default_Handler */
#define N_IRQ 102
typedef void (*vec_t)(void);

uint32_t SystemCoreClock = 16000000u;

#pragma GCC diagnostic push
#pragma GCC diagnostic ignored "-Woverride-init"
__attribute__((section(".isr_vector"), used))
const vec_t vector_table[16 + N_IRQ] = {
    (vec_t)&_estack,
    Reset_Handler,
    NMI_Handler,
    HardFault_Handler,
    MemManage_Handler,
    BusFault_Handler,
    UsageFault_Handler,
    0, 0, 0, 0,
    SVC_Handler,
    DebugMon_Handler,
    0,
    PendSV_Handler,
    SysTick_Handler,
    [16 ... 16 + N_IRQ - 1] = Default_Handler,
    [16 + ADC1_2_IRQn] = ADC1_2_IRQHandler,
    [16 + EXTI15_10_IRQn] = EXTI15_10_IRQHandler,
    [16 + USART1_IRQn] = USART1_IRQHandler,
};
#pragma GCC diagnostic pop

void Reset_Handler(void)
{
    uint32_t *src = &_sidata, *dst = &_sdata;
    while (dst < &_edata)
        *dst++ = *src++;
    for (dst = &_sbss; dst < &_ebss;)
        *dst++ = 0;
    SCB->CPACR |= (0xFu << 20);           /* enable FPU (CP10/CP11) */
    __DSB();
    __ISB();
    SCB->VTOR = (uint32_t)vector_table;
    __libc_init_array();
    main();
    for (;;)
        ;
}

/* Any unexpected interrupt / fault: gates off, then let the watchdog reset us. */
void Default_Handler(void)
{
    TIM1->BDTR &= ~TIM_BDTR_MOE;
    for (;;)
        ;
}

/* newlib stubs (no OS, no file I/O) */
struct stat;
int _close(int f) { (void)f; return -1; }
int _fstat(int f, struct stat *st) { (void)f; (void)st; return -1; }
int _getpid(void) { return 1; }
int _isatty(int f) { (void)f; return 0; }
int _kill(int p, int s) { (void)p; (void)s; return -1; }
int _lseek(int f, int o, int w) { (void)f; (void)o; (void)w; return -1; }
int _read(int f, char *b, int n) { (void)f; (void)b; (void)n; return -1; }
int _write(int f, const char *b, int n) { (void)f; (void)b; return n; }
void _exit(int c) { (void)c; for (;;) ; }
void *_sbrk(int incr)
{
    extern char end;
    static char *brk = &end;
    char *prev = brk;
    uintptr_t limit = (uintptr_t)&_estack - 0x800u;   /* keep 2 KB for the stack */
    if ((uintptr_t)(brk + incr) > limit)
        return (void *)-1;
    brk += incr;
    return prev;
}

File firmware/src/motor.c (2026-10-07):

/*
 * Field oriented control of a hall-sensored hub motor.
 *
 * Runs in the ADC1 injected-end-of-sequence interrupt at 20 kHz:
 *   currents -> Clarke/Park -> PI (d,q) with BEMF feed-forward and
 *   back-calculation anti-windup -> inverse Park -> min/max SVPWM.
 * Torque (iq) command = throttle * i_phase_max, ramped, then clamped by
 *   phase current, battery current (from P = 1.5*vq*iq), regen current,
 *   under-voltage, temperature, speed and stall fold-backs.
 */
#include "motor.h"

#include <math.h>
#include <stdio.h>
#include <string.h>

#include "board.h"
#include "config.h"
#include "drv8353.h"
#include "hall.h"
#include "hw.h"
#include "mathx.h"

motor_t m;
float wh_used, ah_used, wh_regen;

#define DT            CTRL_DT
#define HZ            ((float)PWM_HZ)
#define VMAX_FRAC     0.92f       /* max duty ~0.96: low-side shunt window on two phases */
#define BLOCKING      (FLT_OVERCURRENT | FLT_OVERVOLTAGE | FLT_HALL | FLT_THROTTLE | \
                       FLT_FET_TEMP | FLT_MOTOR_TEMP | FLT_CSA_OFFSET | FLT_DRIVER)
#define LATCHED       (FLT_OVERCURRENT | FLT_HALL | FLT_DETECT | FLT_DRIVER)

static float off_a = 2048, off_b = 2048, off_c = 2048;
static float duty_live[3] = {0.5f, 0.5f, 0.5f};   /* duties during the sample being read */
static float acc_a, acc_b, acc_c;
static uint32_t calib_n;

static float kp, ki;                 /* run gains */
static float kp_det, ki_det;         /* conservative gains for detection */
static float int_d, int_q, vd_out, vq_out;
static float iq_cmd;
static float thr_f;
static uint32_t armed_ticks, thr_bad_ticks, ov_ticks, hall_bad_ticks, idle_ticks;
static uint32_t stall_ticks, fault_ticks;
static int armed;
static int8_t active_dir = 1;
static volatile uint32_t flt_latched, flt_isr, flt_main;
uint16_t drv_status1, drv_status2;          /* DRV8353 fault words at the last trip */
static volatile float derate_temp = 1.0f;
static volatile uint32_t lim_main;
static float ibus_f, power_f;

/* detection */
static int det_what, det_phase;
static uint32_t det_t;
static float det_theta, det_acc_v, det_acc_i, det_v1, det_i1, det_vinj, det_prev_id, det_acc_di;
static uint32_t det_n;
static int8_t det_sign;
static uint32_t det_edges0;
static float det_r, det_l;
static volatile int det_pending;      /* 1 = ISR finished a step, main must post-process */
static char det_msg[128];
static volatile int det_msg_ready;

static void enter(motor_state_t s)
{
    if (s != ST_RUN && s < ST_DET_R)
        pwm_disable();
    m.state = s;
}

void motor_update_gains(void)
{
    float wc = TWO_PI * cfg.bw_hz;
    kp = cfg.motor_l * wc;
    ki = cfg.motor_r * wc;
}

void motor_init(void)
{
    float s, c;
    sincos_f(0.0f, &s, &c);           /* build LUT outside the ISR */
    motor_update_gains();
    kp_det = 0.0003f * TWO_PI * 200.0f;
    ki_det = 0.15f * TWO_PI * 200.0f;
    CoreDebug->DEMCR |= CoreDebug_DEMCR_TRCENA_Msk;
    DWT->CYCCNT = 0;
    DWT->CTRL |= DWT_CTRL_CYCCNTENA_Msk;
    m.dir = 1;
    m.t_fet = m.t_mot = 25.0f;
    calib_n = 0;
    acc_a = acc_b = acc_c = 0.0f;
    flt_latched = 0;
    m.state = ST_CALIB;
#ifndef SIM
    uint32_t t0 = millis();
    while (m.state == ST_CALIB && millis() - t0 < 500)
        ;
#endif
}

/* ------------------------------------------------------------------------ */
/* Duties go through here so the ISR knows which ones were live at the next
   sample: TIM1 (RCR=1) loads them at the valley, the ADC samples at the peak. */
static float duty_cmd[3] = {0.5f, 0.5f, 0.5f};

static void pwm_out(float a, float b, float c)
{
    duty_cmd[0] = a;
    duty_cmd[1] = b;
    duty_cmd[2] = c;
    pwm_set(a, b, c);
}

static void apply_voltage(float vd, float vq, float theta, float vbus)
{
    float s, c;
    sincos_f(theta, &s, &c);
    float va = vd * c - vq * s;              /* alpha */
    float vb = vd * s + vq * c;              /* beta  */
    float pa = va;
    float pb = -0.5f * va + 0.5f * SQRT3 * vb;
    float pc = -0.5f * va - 0.5f * SQRT3 * vb;
    float mx = fmaxf(pa, fmaxf(pb, pc));
    float mn = fminf(pa, fminf(pb, pc));
    float off = 0.5f * (mx + mn);
    float inv = 1.0f / vbus;
    pwm_out(0.5f + (pa - off) * inv, 0.5f + (pb - off) * inv, 0.5f + (pc - off) * inv);
}

/* PI current loop.  Returns 1 if the voltage vector was limited. */
static int current_loop(float idr, float iqr, float id, float iq, float theta_out,
                        float vbus, float p, float i, float ffd, float ffq, float vinj_d)
{
    float vmax = vbus * VMAX_FRAC * INV_SQRT3;
    float ed = idr - id, eq = iqr - iq;
    float nd = int_d + i * DT * ed, nq = int_q + i * DT * eq;
    float vd = p * ed + nd + ffd;
    float vq = p * eq + nq + ffq;
    int lim = 0;
    float mag2 = vd * vd + vq * vq;
    if (mag2 > vmax * vmax) {
        /* scale the vector (keeps its direction), and only let the integrators
           move in the direction that reduces saturation (no dump on transients) */
        float k = vmax / sqrtf(mag2);
        vd *= k;
        vq *= k;
        lim = 1;
        if (ed * vd < 0.0f)
            int_d = nd;
        if (eq * vq < 0.0f)
            int_q = nq;
    } else {
        int_d = nd;
        int_q = nq;
    }
    int_d = clampf(int_d, -vmax, vmax);
    int_q = clampf(int_q, -vmax, vmax);
    vd_out = vd;
    vq_out = vq;
    float vdi = clampf(vd + vinj_d, -vmax, vmax);
    apply_voltage(vdi, vq, theta_out, vbus);
    m.vd = vd;
    m.vq = vq;
    m.mod = sqrtf(vd * vd + vq * vq) / (vbus * INV_SQRT3);
    return lim;
}

static void start_run(float omega)
{
    int_d = 0.0f;
    int_q = 0.0f;
    iq_cmd = 0.0f;
    vd_out = 0.0f;
    vq_out = omega * cfg.motor_flux;
    pwm_out(0.5f, 0.5f, 0.5f);
    pwm_enable();
    idle_ticks = 0;
    stall_ticks = 0;
    m.state = ST_RUN;
}
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

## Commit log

2026-10-06 48V 35A BLDC hub motor controller: KiCad design + STM32G431 FOC firmware
    Hardware (KiCad 7 project, generated from hardware/tools/circuit.py):
    - 6x IPT015N10N5 100V FETs, 3x LM5109B drivers, in-line 0.5 mOhm phase
    shunts with INA240A2 current amps, 6x220uF + ceramics DC link, TVS
    - LM5164 48->12V and 48->5V bucks, AP2112 3.3V LDO
    - soft power latch for a momentary button (switch only sees 3.3V)
    - JST-PH connectors: halls+motor NTC, throttle, FWD/REV, brake, power
    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
    [bldc48.kicad_pcb, bldc48.kicad_sch, bom.csv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]
2026-10-06 Route the PCB and add 3D renders
    - gen_pcb.py: structured placement (one column per phase: high/low FET,
    shunt, motor pad; driver and current amp alongside), 190x120 mm board,
    2 mm spacing for fan-out
    - route_pcb.py: Specctra export, Freerouting (headless), own SES import
    (KiCad 7 has no scripted SES import) that restores layer-change vias the
    router omits, In1 GND / In2 +48V,+3V3 planes, outer-layer high-current
    pours, via arrays in power pads, zone fill + DRC
    - routed board: 0 unconnected pads, 0 clearance errors in KiCad DRC
    - render3d/: VRML export with KiCad 3D models + headless three.js renderer
    - hardware/renders/: 3D views, routing and per-layer images, GLB model
    Co-Author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
    [bldc48.kicad_pcb]
2026-10-07 Rev B: fix power terminals and design-review findings
    Layout (hand-placed power stage):
    - BAT+/BAT- and MOTOR A/B/C are now M5 plated bolt terminals at the board
    edges (battery 36 mm apart on the left edge, motors under their shunts),
    replacing 5x10 mm SMD solder pads that sat 7.5 mm apart
    - per phase: driver | high FET over low FET (drain tabs up, compact switch
    node) | Kelvin shunt + INA240; DC-link ceramics at the low-side sources
    - FET NTC moved next to the middle low-side FET
    - rule area keeps tracks off the inner planes under the power stage
    - pours sized from real TOLL pad outlines; solid plane connections
    - hand route for the one connection Freerouting leaves open; routing
    se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
    [bldc48.kicad_pcb, bldc48.kicad_sch, bom.csv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]
2026-10-07 Rev C: compact 188x74 mm layout, re-routed, DRC clean; JLCPCB cost notes
    - Repack the power stage into 38 mm phase columns and the logic into a 52 mm
    strip; smaller SRN8040TA buck inductors
    - Re-route with Freerouting; record the LATCH_B hand route and move
    references that land on neighbouring silkscreen
    - Regenerate BOM, schematic PDF, layer images and 3D renders (stand-in model
    for the SRN8040TA)
    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
    [bldc48.kicad_pcb, bom.csv, bridge.kicad_sch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]
2026-10-07 BOM: Bourns CSS4J-4026R-L500F as the JLCPCB-stocked shunt
    Claude-Session: https://claude.ai/code/session_01KE5bAkgcicsoh5erUtagKE
    [bom.csv, bridge.kicad_sch]
2026-10-07 Use Bourns CSS4J-4026R-L500F shunts (JLCPCB C2076423)
    Same 0.5 mOhm / 1 % / 5 W and land pattern as the BVR 4026 footprint, so the
    layout and firmware scaling are unchanged. Update the cost estimate.
    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
    [bom.csv, bridge.kicad_sch]
2026-10-07 BOM: LCSC part numbers, replacements for unstocked parts; revise cost
    Bulk 220 uF/100 V caps are not stocked at LCSC: buy separately or use global
    sourcing. Add a stocked alternative for the 33 uH inductor. Fix the cost
    total (the low end did not match the sum of the rows).
    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
    [bom.csv, bridge.kicad_sch, power.kicad_sch]
2026-10-07 Rev D (in progress): compact placement tooling, stocked bulk caps
    - Skyline packer with 90-degree rotation for small parts (fills regions
    far better than the row packer)
    - Fix reference-overlap check: SWIG proxies are never identical, so every
    reference was compared with itself and hidden
    - Rev D geometry: 185 x 66 mm, motor terminals beside the DC-link ceramics,
    narrower battery strip (board file stays rev C until routing is done)
    - Bulk caps: Aishi ERS1KM221W25OT (LCSC C106684)
    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
    [bridge.kicad_sch]
2026-10-07 Keep signal tracks off the phase-output and switch-node pours
    Outer-layer rule areas over each phase strip (shunt to motor terminal) and
    switch node; a signal crossing one split the pour on that layer. Reference
    placement now also avoids pads, own silkscreen and the board edge.
    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
    [gen_pcb.py]
2026-10-07 Router: leave phase nets to the pours, no switch-node keepout
    The phase strips are track keep-outs, so the shunt-to-terminal connection
    is taken out of the Specctra netlist (the pours make it). The switch-node
    keepout is dropped: the driver HS pin has to reach that copper.
    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
2026-10-07 Rev D: 185 x 66 mm board, routed, DRC clean, all parts stocked at LCSC
    - Motor terminals beside the DC-link ceramics, routing channel underneath;
    17 mm battery strip; skyline-packed controller strip
    - Phase strips free of signal tracks (both layers carry the motor current)
    - Two INA240 supply taps the router left open closed with recorded routes
    - Aishi ERS1KM221W25OT bulk caps (LCSC C106684)
    - New renders, layer images, BOM, schematic PDF; README rev D + cost
    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
    [bldc48.kicad_pcb, bom.csv]
2026-10-07 Rev E: four 1000 uF/100 V bulk caps, 180 x 69.5 mm, routed, DRC clean
    - 4 x Aishi ERS1KM102M35OT (LCSC C724666, 18 x 35 mm) spread over the
    bridges instead of 8 x 220 uF: 4000 uF, half the parts
    - Rerouted (100 passes); the one open INA240 supply tap closed with a route
    from the new astar_route.py grid router, ending on a via into the +3V3 plane
    - RIP_UP drops a 139 mm Freerouting detour on the phase C low-side gate drive;
    it is re-made locally (24 mm, like phases A/B). All phase and switch-node
    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
    [bldc48.kicad_pcb, bom.csv, bridge.kicad_sch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]
2026-10-07 Rev F (in progress): DRV8353RS redesign for a 90 x 64.5 mm board
    - Circuit: DRV8353RS gate driver + CSAs + 5 V buck replaces 3x LM5109B,
    3x INA240 and both LM5164s; low-side Kelvin shunts; 12 AWG solder-wire
    pads; JST-GH connectors; 3x 1000 uF bulk caps; project symbol/footprint
    library (DRV8353RS symbol + TI RGZ footprint from flatmcu, MIT)
    - Firmware: SPI1 driver for the DRV8353 (config + readback + lock, fault
    readout, 'drv' command), ADC sampling at the PWM peak via TIM1 TRGO2,
    high-duty phase rebuilt from the other two, DRIVER fault; sim models the
    low-side shunt blind window and a driver fault - all checks pass
    - Placement for the two-sided 3-column layout; router keepouts,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
    [bldc48.kicad_sch, bridge.kicad_sch, io.kicad_sch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]
2026-10-07 Rev F: room for the DRV8353 fan-out; grid-router finishing pass
    - 2.5 mm fan-out ring around the DRV8353, MCU beside it (bottom side)
    instead of underneath; board 90 x 68.5 mm
    - route_pcb: route connections still open after Freerouting and the short
    repairs with astar_route.py (fenced off the power array first)
    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
    [gen_pcb.py]
2026-10-07 Router: GND / +3V3 fan-out vias into the planes before autorouting
    Every GND and +3V3 SMD pad outside the power array gets a short stub and a
    via into In1 / In2; the router no longer draws these nets (their wiring is
    exported as fixed), which frees most of the routing space on the small
    two-sided board. Option to skip the slow DRC-checked short repairs.
    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
2026-10-07 Rev F routability: B.Cu open for gate drive, solid In1 GND, DRV buck parts at its pins
    - power-copper keepouts only on F.Cu (it carries the motor current); gate and
    sense traces can run up the columns on B.Cu
    - In1 is a solid GND plane (no tracks); In2 is +48 V under the array and a
    signal layer with a +3V3 fill elsewhere; only GND uses fan-out vias
    - DRV8353 buck passives (BST, RT, RCL, VCC, FB network) packed at its pins;
    DRV rotation also faces the buck pins towards the inductor
    - grid router: drill spacing to every via, pours not walls when unfenced;
    repair passes skip the plane nets
    Claude-Session: https://claude.ai/code/s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
    [gen_pcb.py]
2026-10-07 Router: In1 as a power layer for Freerouting (its wire keep-outs block vias)
    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
2026-10-07 Rev F placement: I/O conditioning on the bottom side under the connectors
    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
2026-10-07 Router tools: per-run board path / height overrides, per-process DRC probe file
    Lets several routing variants run in parallel.
    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
2026-10-07 route_pcb: wider GND fan-out search and exposed-pad ties for ground pins
    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
2026-10-07 route_pcb: second fan-out pass with pin-width stubs along the pin for fine-pitch ground pins
    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
2026-10-07 Router: second fan-out pass keeps clear of the SES wiring; stuck plane pins get a grid-routed via
    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
2026-10-07 Router: plane pins with no fan-out room stay in the DSN for Freerouting; import its extra plane wiring
    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
2026-10-07 Rev F BOM and schematic PDF
    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
    [bom.csv]
2026-10-07 gen_pcb: phase column order follows the DRV8353 pin order (C-B-A, BLDC_COLS overrides)
    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
2026-10-07 Router: route items still cut off after the pour fill into their own net's pour copper
    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
2026-10-07 Grid router: grid aligned to the start pin (fine-pitch escapes), both directions tried; SES avoidance opt-in
    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
2026-10-07 gen_pcb: DRV8353 passives placed at the pins they serve (buck parts by the buck pins)
    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
2026-10-07 Router: fixed SW sense-tap via per phase between the high-side source and low-side drain, beside the gate pin
    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
2026-10-07 Router: power via arrays only in the power array (no via through a far-side pad); stitch GND pour islands
    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
2026-10-07 Placement deterministic across runs (sorted net sets); move fan-out vias the router crowded
    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
2026-10-08 gen_pcb: MCU on the bottom side right under the DRV8353's PWM / SPI pins
    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
2026-10-08 Grid router: fine-pitch pins entered and left through a point past the pin tip
    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
2026-10-08 Signal clearance 0.15 mm (0.2 mm tracks): more routing room between the DRV8353 and the MCU
    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
2026-10-08 Router: stitch cut-off low-side / switch-node pour pieces; more clearance margin for Freerouting
    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
2026-10-08 README: rev F architecture, connectors, driver fault, supplies (board numbers pending)
    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
2026-10-08 MCU turned so its PWM / SPI pins face the DRV8353; fixed hash seed for rebuilds; grid-router exit and via-spacing fixes
    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
    [gen_pcb.py]
2026-10-08 gen_pcb: routing channel between the DRV8353 ring and the MCU (BLDC_MCU_DY)
    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
2026-10-08 Rev F board: 90 x 95 mm, 4 layers, two-sided, fully routed, DRC 0 violations / 0 unconnected
    Default board height 95 mm; SES placement restore fixed for back-side parts at 90/270 deg;
    silkscreen title and BAT- label moved clear of pads.
    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
    [bldc48.kicad_pcb]
2026-10-08 README: rev F board, routing flow, cost (two-sided PCBA), layout rules, review items, sim results
    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

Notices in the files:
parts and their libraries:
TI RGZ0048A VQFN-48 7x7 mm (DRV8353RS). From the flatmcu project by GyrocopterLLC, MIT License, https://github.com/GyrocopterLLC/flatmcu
